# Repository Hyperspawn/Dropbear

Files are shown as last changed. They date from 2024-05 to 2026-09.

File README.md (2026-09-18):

<p align="center">
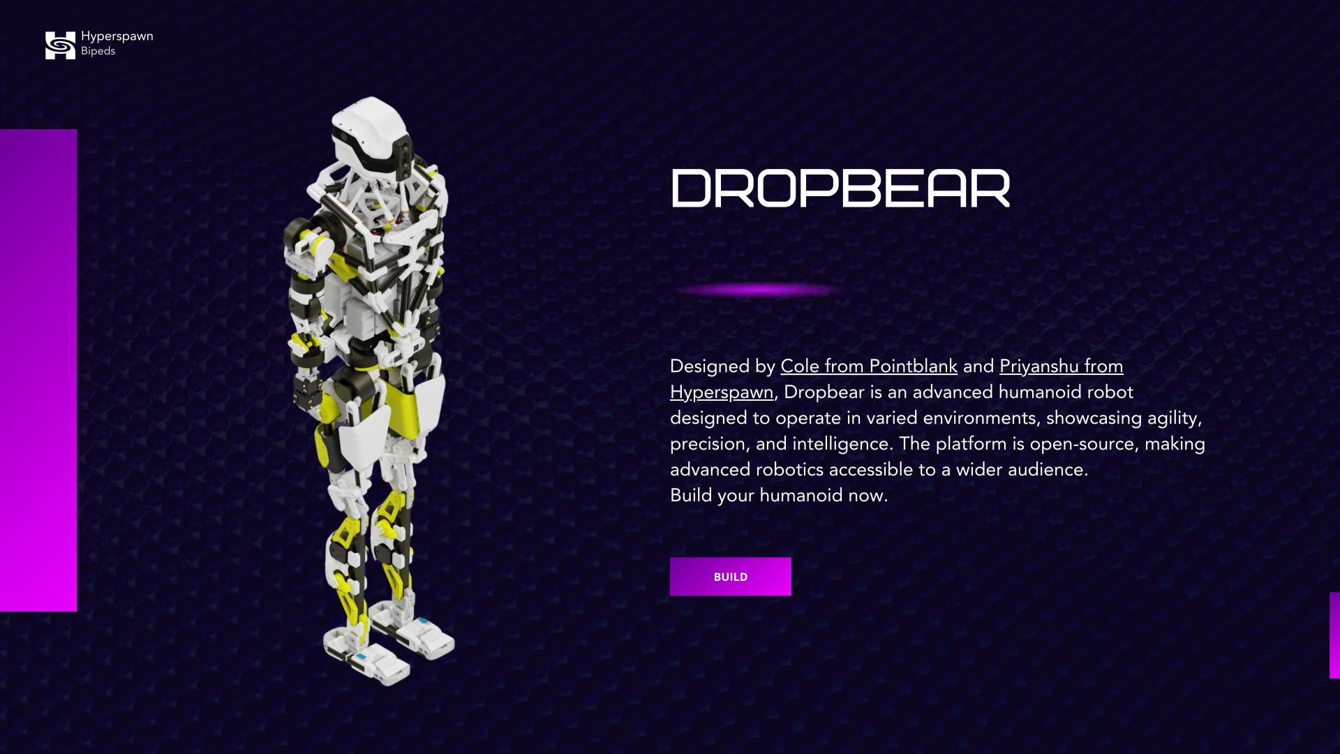
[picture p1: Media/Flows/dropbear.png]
Dropbear humanoid robot
  
</p>

# Dropbear

### A humanoid you can build, understand, and make your own.

Dropbear is a full-size humanoid robotics project by [Hyperspawn](https://hyperspawn.org) and [Pointblank](https://www.pointblankllc.com/). Mechanical designs, printable parts, robot models, and control research give you places to start across the whole robot—from a single assembly on your workbench to locomotion experiments in simulation.

The aim is to make building and using a humanoid feel approachable: find the parts, see how they fit, try a movement, understand what happened, and keep improving it. The [platform](https://hyperspawn.org/platform) brings the build and robot tools into one place.

**[Open the platform →](https://hyperspawn.org/platform)** · [Try the simulator](https://hyperspawn.org/sim) · [Explore the hardware](https://github.com/Hyperspawn/dropbear_hardware) · [Join the community](https://hyperspawn.org/community)

## Start with something you can do today

| I want to… | Start here | First step |
|---|---|---|
| Explore Dropbear | [Browser simulator](https://hyperspawn.org/sim) | Open the scene and explore the robot before setting up a development environment. |
| Build my own | [Build platform](https://hyperspawn.org/platform) | Open the Workshop, choose an assembly, and review its parts and prints. |
| Print a part or assemble a limb | [Printable parts](https://github.com/Hyperspawn/dropbear_printables) | Choose a subassembly and open its prepared `.3mf` plates or individual STL files. |
| Work on walking | [Locomotion](https://github.com/Hyperspawn/dropbear-locomotion) | Follow the setup guide, load a published checkpoint, and use the interactive viewer. |
| Observe connected controllers | [dropbear_control](https://github.com/robit-man/dropbear_control) | Run the local dashboard, open `/?live=1`, and use the Devices view for receive-only leg state and firmware diagnostics. |
| Change the mechanical design | [Hardware](https://github.com/Hyperspawn/dropbear_hardware) | Open the full assembly or a component in CAD. |

You can begin with a head, an arm, or a simulated robot. Each is a useful project in its own right.

## Connected robot control and firmware

Use [`robit-man/dropbear_control`](https://github.com/robit-man/dropbear_control) for the browser digital twin, live USB leg observation, raw serial diagnostics, controller health, and guarded firmware compilation/upload. Its physical command channel remains locked behind staged acknowledgements; live observation starts as receive-only.

```bash
git clone https://github.com/robit-man/dropbear_control.git
cd dropbear_control
python3 web/serve.py 8000
```

Open <http://localhost:8000/?live=1&renderer=swiftshader>. Select **Connected ESP32 devices** to inspect both leg streams, compile a trusted firmware source, or review an upload before its physical safety interlock is released.

The controller sources live in [`Control System/Low Level Control`](https://github.com/Hyperspawn/Dropbear/tree/main/Control%20System/Low%20Level%20Control):

| Firmware | Use |
|---|---|
| [`firmware_full_libs_neck.ino`](https://github.com/Hyperspawn/Dropbear/blob/main/Control%20System/Low%20Level%20Control/firmware_full_libs_neck.ino) | Recommended universal Behemoth image. One build supports left leg, right leg, center IMU, or head/neck roles, exposes the role-named captive portal, boots leg output stopped, and guards web motion with an expiring three-stage interlock. |
| [`esp32_devkitc_v4_hybrid.ino`](https://github.com/Hyperspawn/Dropbear/blob/main/Control%20System/Low%20Level%20Control/esp32_devkitc_v4_hybrid.ino) | Hybrid leg controller retained for existing PWM/CAN deployments. |
| [`esp32_devkit_v1_observation_safe.ino`](https://github.com/Hyperspawn/Dropbear/blob/main/Control%20System/Low%20Level%20Control/esp32_devkit_v1_observation_safe.ino) | Observation-only migration image. Motion commands stay disabled while five AS5600 and six motor-native CAN angles are reported. |
| [`esp32_devkit_v1.ino`](https://github.com/Hyperspawn/Dropbear/blob/main/Control%20System/Low%20Level%20Control/esp32_devkit_v1.ino) | Legacy/development leg controller. Keep it for compatibility and comparison; use Behemoth for new universal deployments. |

Read the [low-level firmware guide](https://github.com/Hyperspawn/Dropbear/blob/main/Control%20System/Low%20Level%20Control/README.md) and [Behemoth role/commissioning guide](https://github.com/Hyperspawn/Dropbear/blob/main/Control%20System/Low%20Level%20Control/BEHEMOTH.md) before selecting an image. The tracked [`partitions.csv`](https://github.com/Hyperspawn/Dropbear/blob/main/Control%20System/Low%20Level%20Control/partitions.csv) gives the application 2.5 MiB while retaining the Arduino default SPIFFS settings region at `0x290000`. The `dropbear_control` uploader reads the connected ESP32 partition table first and refuses a mismatched layout.

## From files to a robot on your workbench

The design is split into subassemblies so you can inspect, print, assemble, and revise one part at a time. The hardware repository includes full-robot STEP and Fusion archives, alongside separate arms, legs, head, pelvis, and torso designs. The print repository organizes parts and plates by assembly.

<p align="center">
  <a href="https://github.com/Hyperspawn/dropbear_hardware">
    CAD render of the Dropbear right arm assembly
    CAD render of the Dropbear right leg assembly
  </a>
</p>

*Right arm and right leg CAD renders from the hardware repository.*

1. **Choose your assembly.** Use the [Workshop](https://hyperspawn.org/platform/build) and [CAD files](https://github.com/Hyperspawn/dropbear_hardware) to understand the parts and how they connect.
2. **Plan the parts and prints.** Review the [bill of materials](https://github.com/Hyperspawn/dropbear_bom/blob/main/bom.md), then select the matching [print files and settings](https://github.com/Hyperspawn/dropbear_printables). You can print them yourself or use a print service.
3. **Assemble and document.** Follow the relevant [assembly documentation](https://github.com/Hyperspawn/dropbear_docs/tree/main/docs/03-assembly). Keep track of the design revision, substitutions, and anything the next builder should know.
4. **Bring up one subsystem at a time.** Review the [current low-level control source](https://github.com/Hyperspawn/Dropbear/tree/main/Control%20System/Low%20Level%20Control) and use [dropbear_control](https://github.com/robit-man/dropbear_control) for versioned observation, health, compile, and guarded upload. Establish wiring, joint directions, limits, and calibration before attempting coordinated motion.

Build files, documentation, and control software are evolving at different speeds. Match revisions across them before ordering parts or powering an assembly. Use the BOM to develop a budget for your chosen configuration and local suppliers.

## Walking you can inspect and reproduce

The [Dropbear locomotion project](https://github.com/Hyperspawn/dropbear-locomotion) publishes an Isaac Lab training environment, robot USD, policy checkpoints, evaluation reports, and an interactive viewer. You can load a policy, steer a simulated Dropbear, inspect its motion, and continue training.

Dropbear locomotion training shown in the interactive viewer (https://github.com/Hyperspawn/dropbear-locomotion)

*Isaac Lab simulation, with a training environment mirrored into the live viewer.*

The published **v0.1.0 flat-ground policy completed 128 simulation trials with zero falls**: 32 each for forward, backward, left, and right commands. Each trial ran for 20 seconds on a plane, with pushes disabled and a commanded speed of 0.20 m/s. Backward and lateral speed tracking remain areas for improvement. [Read the evaluation results](https://github.com/Hyperspawn/dropbear-locomotion/blob/main/evaluation/cardinal_0.20_strict_128.json).

The **v0.2.0 terrain checkpoint is experimental**, adding terrain observations and low-obstacle training. These are simulation releases; physical walking and robustness require separate validation.

**[Run the locomotion quick start →](https://github.com/Hyperspawn/dropbear-locomotion#quick-start)**

## Find the part of the project you need

This repository is the project’s front door and contains the original hardware, software, and media. More focused work lives in the repositories below.

| Area | Repository | What you will find |
|---|---|---|
| Mechanical design | [dropbear_hardware](https://github.com/Hyperspawn/dropbear_hardware) | Full assembly CAD and mechanical subassemblies. |
| 3D printing | [dropbear_printables](https://github.com/Hyperspawn/dropbear_printables) | Prepared print plates, individual parts, and print guidance. |
| Parts and sourcing | [dropbear_bom](https://github.com/Hyperspawn/dropbear_bom) | Purchased components and assembly-level cost estimates. |
| Build documentation | [dropbear_docs](https://github.com/Hyperspawn/dropbear_docs) | Assembly guides and sections for electronics, calibration, testing, and operation. |
| Robot descriptions | [dropbear_urdf](https://github.com/Hyperspawn/dropbear_urdf) · [dropbear_mjcf](https://github.com/Hyperspawn/dropbear_mjcf) | Robot models and meshes for visualization and simulation. |
| Simulation workspace | [dropbear_sim](https://github.com/Hyperspawn/dropbear_sim) | Links and submodules for the simulation projects. |
| Locomotion research | [dropbear-locomotion](https://github.com/Hyperspawn/dropbear-locomotion) | Training, published policies, live viewing, and evaluations. |
| Embedded control | [Current low-level control](https://github.com/Hyperspawn/Dropbear/tree/main/Control%20System/Low%20Level%20Control) · [dropbear_control](https://github.com/robit-man/dropbear_control) | Versioned ESP32/CAN firmware plus the connected-robot dashboard, diagnostics, compile, and guarded upload workflow. |
| Motor tools | [myactuator-can](https://github.com/Hyperspawn/myactuator-can) | MyActuator driver and diagnostics work. |

[Browse all Hyperspawn repositories →](https://github.com/orgs/Hyperspawn/repositories)

## What we are working toward

We want a humanoid that people can understand well enough to repair, adapt, teach, and put to use. That means connecting the practical details—parts, wiring, calibration, and control—with simulation, teleoperation, and learned behavior.

The next steps include more complete build guidance, better locomotion across terrain, and bringing control and learning workflows onto physical hardware. Teleoperation and language-driven behavior are development directions; their integration into a dependable whole-robot system is ongoing.

The useful unit of progress is something another person can try: a better joint, a clearer assembly step, a reproducible policy, or a physical test with enough detail to repeat it.

## Build with us

Share a build photo, improve a part, reproduce an experiment, or fix the instruction that slowed you down. Small improvements travel a long way when the next person builds from the same files.

- **Building hardware?** Include the assembly revision, material, print settings, and photos of the fit or failure.
- **Working on software or policies?** Include the environment, configuration, and results; say whether the test ran in simulation or on hardware.
- **Improving documentation?** Show the missing step, the corrected part, or the explanation you wish you had.

Open an issue or pull request in the relevant repository. For general project questions, use [Dropbear issues](https://github.com/Hyperspawn/Dropbear/issues) or the [community](https://hyperspawn.org/community). The documentation project also has [contribution guidelines](https://github.com/Hyperspawn/dropbear_docs/blob/main/CONTRIBUTING.md).

## Credits and licensing

Dropbear is developed by **Hyperspawn and Pointblank**, with contributions from builders and researchers across the project. Locomotion training lineage and contributor credits are documented in the [locomotion repository](https://github.com/Hyperspawn/dropbear-locomotion#training-lineage-and-credits).

This repository uses the [Hyperspawn License](https://github.com/Hyperspawn/Dropbear/blob/main/LICENSE), which restricts use to non-commercial purposes and requires a separate license for commercial use. Related repositories and assets carry their own terms; check the license supplied with the files you use.

---

[Start a build](https://hyperspawn.org/platform) · [Try the simulator](https://hyperspawn.org/sim) · [Meet the community](https://hyperspawn.org/community)

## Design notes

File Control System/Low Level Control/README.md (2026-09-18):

# Dropbear ESP32 Low-Level Control

Dropbear control hardware

Low-level ESP32 firmware for the Dropbear bipedal robot.

For connected-robot visualization, receive-only USB telemetry, raw controller
serial, and guarded compile/upload, use the
[`dropbear_control` dashboard](https://github.com/robit-man/dropbear_control).
The firmware choices in this directory are:

| Source | Intended use |
|---|---|
| `firmware_full_libs_neck.ino` | Recommended universal Behemoth build for left leg, right leg, center, and head/neck roles. Its role-named captive portal exposes live CAN/AS5600 state and guarded control; leg output boots stopped and web motion requires the timed three-stage interlock. |
| `esp32_devkitc_v4_hybrid.ino` | Existing hybrid leg PWM/CAN deployments. |
| `esp32_devkit_v1_observation_safe.ino` | Fail-closed observation migration with no motion command path. |
| `esp32_devkit_v1.ino` | Legacy/development leg implementation retained for compatibility. |

## Dashboard observation protocol

All four images answer `version`, `/version`, `capabilities`, and `health` on
USB Serial. They also accept `observe on` and `observe off`; these commands
only select telemetry and never change `playMode` or motor output.

Behemoth requires every command to carry its saved role, for example:

```text
<DB1:LEFTLEG> version
<DB1:RIGHTLEG> health
<DB1:RIGHTLEG> observe on
```

Hybrid, V1, and Observation Safe retain bare legacy command framing. The
firmware reports the exact choice instead of making the host guess:

```text
DBV1,<role>,<firmware>,<command_protocol>,<telemetry_protocol>,<capability;list>
DBH1,<role>,<ms>,<overall>,<runtime>,<can>,<sensor_mask>,<motor_fresh_mask>,<motor_control_mask>,<alignment_fault_mask>,<queries>,<responses>,<query_failures>,<malformed>,<can_failures>
```

Behemoth, Hybrid, and V1 emit `DB3`: five external sensor degrees, six raw
RMD `0x92` multi-turn degrees, six CAN angles aligned at restart to the
external sensor coordinates, then three six-bit freshness/control/fault masks.
Observation Safe emits `DB2` with the five external and six raw CAN fields.
The captive portals expose the same identity at `GET /api/version`.

All dashboard builds copy this directory's `partitions.csv`. It provides a
2.5 MiB application region while preserving the standard deployed SPIFFS
settings region at `0x290000` with size `0x160000`. The dashboard uses
`EraseFlash=none`, reads the target partition table before upload, and holds
the upload if the installed SPIFFS offset or size differs.

This controller is designed around **one ESP32 per leg**, an **MCP2515 CAN controller**, MyActuator/RMD-class CAN actuators, and five external analog joint-angle sensors per leg. The firmware performs high-rate joint sensing, optional joint-space impedance control, deterministic CAN torque output, persistent calibration/configuration, and serial command handling.

The current firmware is intentionally a **torque-control architecture**, not an actuator-internal absolute-position architecture. It sends MyActuator `0xA1` torque/current commands during normal operation and `0x81` stop commands when stopping a leg.

The firmware file documented here is:

```text
Control System/
└── Low Level Control/
    └── esp32_devkit_v1.ino
```

---

## Contents

- [System architecture](#system-architecture)
- [Controller roles](#controller-roles)
- [Hardware](#hardware)
- [Pinout](#pinout)
- [CAN configuration](#can-configuration)
- [Actuator IDs](#actuator-ids)
- [External joint sensors](#external-joint-sensors)
- [Boot sequence](#boot-sequence)
- [FreeRTOS runtime architecture](#freertos-runtime-architecture)
- [CAN command arbitration](#can-command-arbitration)
- [Direct torque control](#direct-torque-control)
- [Impedance control](#impedance-control)
- [Joint constraints](#joint-constraints)
- [Sensor calibration](#sensor-calibration)
- [Torque-direction calibration](#torque-direction-calibration)
- [Stop behavior](#stop-behavior)
- [Center / IMU mode](#center--imu-mode)
- [Persistent configuration](#persistent-configuration)
- [Serial interface](#serial-interface)
- [Command reference](#command-reference)
- [Recommended commissioning procedure](#recommended-commissioning-procedure)
- [Safety and current limitations](#safety-and-current-limitations)
- [Dependencies](#dependencies)
- [Relationship to `myactuator-can`](#relationship-to-myactuator-can)
- [Legacy behavior removed or changed](#legacy-behavior-removed-or-changed)

---

# System architecture

The controller is split into three primary real-time paths:

```text
                         HIGH-LEVEL / SERIAL COMMAND
                                   │
                  ┌────────────────┴────────────────┐
                  │                                 │
          direct torque setpoint            impedance target
                  │                                 │
                  │                          q*, dq*
                  │                                 │
                  │                    external joint sensor
                  │                                 │
                  │                          state estimate
                  │                                 │
                  │                     impedance controller
                  │                                 │
                  └──────────────┬──────────────────┘
                                 │
                          command selection
                                 │
                         torque saturation
                                 │
                         single CAN writer
                                 │
                    MyActuator 0xA1 command
                                 │
                              actuator
```

The key architectural rule is:

> **Only the CAN output task performs normal actuator transmission.**

The impedance task computes desired torque but does not transmit CAN frames. Direct torque commands also only update setpoints. The CAN output task is the single periodic owner of normal motor output.

This prevents the previous architecture from having multiple FreeRTOS tasks independently transmit competing torque values to the same actuator.

---

# Controller roles

Each ESP32 stores one of three roles in SPIFFS:

```text
left
right
center
```

## `left`

The controller:

- initializes MCP2515 CAN,
- reads the five local analog joint sensors,
- runs left-leg impedance controllers,
- sends commands only to the six left-leg actuator CAN IDs,
- accepts left-leg torque and impedance commands.

## `right`

The controller:

- initializes MCP2515 CAN,
- reads the five local analog joint sensors,
- runs right-leg impedance controllers,
- sends commands only to the six right-leg actuator CAN IDs,
- accepts right-leg torque and impedance commands.

## `center`

The controller:

- does not initialize the MCP2515 CAN control path,
- does not start leg sensor/control/CAN-output tasks,
- starts the IMU polling task,
- polls I²C addresses `0x68` through `0x6C`,
- prints raw accelerometer and gyroscope data over Serial.

Changing between a leg role and `center` is persisted immediately, but **a reboot is required for the correct task/hardware set to be created**.

Changing directly between `left` and `right` uses the same leg task set and can take effect without changing the physical task topology, although the robot should still be stopped before changing roles.

---

# Hardware

The current low-level leg controller expects:

- ESP32 DevKit V1 / classic ESP32
- MCP2515 CAN controller
- MCP2515 module fitted with an **8 MHz oscillator**
- CAN transceiver associated with the MCP2515 module
- MyActuator/RMD-compatible CAN actuators
- five analog joint-angle signals per leg
- optional I²C IMUs for center mode
- USB serial connection for configuration/debugging

The code uses a 12-bit ADC configuration:

```cpp
analogReadResolution(12);
```

which produces nominal readings from `0` through `4095`.

---

# Pinout

## MCP2515 / SPI

| Function | ESP32 GPIO | Notes |
| --- | ---: | --- |
| MCP2515 CS  | **5** | Active chip-select used by `MCP_CAN` |
| SPI SCK | **18** | Explicitly initialized |
| SPI MISO | **19** | Explicitly initialized |
| SPI MOSI | **23** | Explicitly initialized |
| MCP2515 INT | **17** | Configured as `INPUT_PULLUP`; current firmware does not use interrupt-driven CAN RX |

SPI initialization:

```cpp
SPI.begin(18, 19, 23, 5);
```

The current controller is transmit-oriented. The MCP2515 interrupt pin is retained in the hardware definition for future receive/interrupt handling, but no ISR is currently attached.

## I²C

| Function | ESP32 GPIO |
| --- | ---: |
| SDA | **21** |
| SCL | **22** |

Initialization:

```cpp
Wire.begin(21, 22);
```

## Analog joint sensors

| Joint measurement | ESP32 GPIO |
| --- | ---: |
| Outer calf | **14** |
| Inner calf | **27** |
| Hip pitch | **26** |
| Knee | **25** |
| Hip roll / butt | **33** |

There is currently **no dedicated external analog hip-yaw input**.

---

# CAN configuration

The MCP2515 is configured as:

```text
Bit rate:       1,000,000 bit/s
MCP2515 clock:  8 MHz
Mode:           normal
CAN frame type: standard 11-bit identifier
```

Initialization is equivalent to:

```cpp
CAN.begin(MCP_ANY, CAN_1000KBPS, MCP_8MHZ);
CAN.setMode(MCP_NORMAL);
```

If MCP2515 initialization fails, firmware prints an error and intentionally stops in an infinite delay loop rather than entering operation without CAN.

---

# Actuator IDs

The twelve robot actuator IDs are preserved.

| Internal index | Side  | Joint |  CAN ID |
| ---: | ----- | --- | ---: |
| 0 | Right | Outer calf | `0x144` |
| 1 | Left  | Outer calf | `0x141` |
| 2 | Right | Inner calf | `0x143` |
| 3 | Left  | Inner calf | `0x142` |
| 4 | Right | Knee | `0x148` |
| 5 | Left  | Knee | `0x145` |
| 6 | Right | Hip pitch  | `0x147` |
| 7 | Left  | Hip pitch  | `0x146` |
| 8 | Right | Hip yaw | `0x14C` |
| 9 | Left  | Hip yaw | `0x149` |
| 10 | Right | Hip roll | `0x14B` |
| 11 | Left  | Hip roll | `0x14A` |

The array is deliberately interleaved:

```text
even index -> right leg
odd index  -> left leg
```

This allows the CAN output task to select a leg with a stride of two.

### Left controller transmits only

```text
0x141
0x142
0x145
0x146
0x149
0x14A
```

### Right controller transmits only

```text
0x144
0x143
0x148
0x147
0x14C
0x14B
```

A left ESP therefore no longer sends zero or control traffic to right-leg motors, and a right ESP no longer sends traffic to left-leg motors.

---

# External joint sensors

Five local joint signals are sampled by each leg controller.

The processing chain is:

```text
ADC
 │
 ├─ 12-bit analogRead()
 │
 ├─ 10-sample moving average
 │
 ├─ convert ADC count to 0..360 degrees
 │
 ├─ apply selected-leg offset unless raw mode is enabled
 │
 └─ wrap result into [0, 360)
```

ADC-to-angle conversion is:

```text
angle = ADC × 360 / 4096
```

## Sensor acquisition rate

The sensor task runs every:

```text
1 ms
```

or approximately:

```text
1000 Hz
```

The moving-average window is ten samples, so the filter spans approximately 10 ms at the nominal task rate.

## Serial telemetry rate

When `playMode` is active in leg mode, normalized angles are printed approximately every:

```text
20 ms
```

or:

```text
50 Hz
```

The telemetry format is CSV:

```text
outer,inner,hipPitch,knee,hipRoll
```

Example:

```text
181.2,179.7,176.4,183.1,180.0
```

Command/status text shares the same Serial connection, so consumers of the stream must be able to distinguish CSV telemetry lines from human-readable command responses.

---

# Boot sequence

On reset, the firmware performs the following sequence.

## 1. Serial

Starts:

```text
115200 baud
```

## 2. Synchronization primitives

Creates:

- serial mutex,
- CAN mutex,
- state mutex.

## 3. ADC and I²C

Configures 12-bit ADC resolution and starts I²C on GPIO 21/22.

## 4. SPIFFS

Mounts SPIFFS using:

```cpp
SPIFFS.begin(true)
```

The `true` argument allows formatting if mounting fails.

If SPIFFS still cannot be mounted, the controller halts.

## 5. Configuration

The firmware attempts to load:

```text
/config.txt
```

If no configuration file exists, the controller prompts:

```text
Enter 'left' for left leg, 'right' for right leg, or 'center' for IMU center.
```

The selected role is then saved.

## 6. Role-specific initialization

### Leg role

The controller:

1. configures MCP2515 INT GPIO 17 as input pull-up,
2. initializes SPI,
3. starts MCP2515 at 1 Mbit/s / 8 MHz,
4. switches MCP2515 to normal mode,
5. primes the ten-sample joint sensor filters,
6. starts sensor, impedance, CAN-output, and serial tasks.

### Center role

The controller starts:

- IMU task,
- serial-command task.

CAN is not initialized in center mode.

## 7. Play state

At the end of setup:

```cpp
playMode = true;
```

Therefore:

- a leg controller begins its normal 100 Hz CAN output loop immediately,
- all initial torque setpoints are zero, so initial normal output is zero `0xA1` torque,
- a center controller begins IMU polling immediately.

This startup behavior is intentional and preserves the previous controller's automatic active state while ensuring the initial commanded torque values are zero.

---

# FreeRTOS runtime architecture

## Leg controller tasks

| Task | Core | Priority | Period | Responsibility |
| --- | ---: | ---: | ---: | --- |
| `readAndComputeTask` | 0 | 2 | 1 ms | ADC acquisition, filtering, normalization, 50 Hz telemetry |
| `impedanceControlTask` | 1 | 2 | 10 ms | Compute impedance torque setpoints |
| `canOutputTask` | 1 | 3 | 10 ms | Sole periodic actuator CAN transmitter |
| `checkChiralityTask` | 1 | 1 | ~10 ms poll | Serial command parser |

## Center controller tasks

| Task | Core | Priority | Period | Responsibility |
| --- | ---: | ---: | ---: | --- |
| `imuReadTask` | 0 | 1 | 10 ms | Poll raw IMU data |
| `checkChiralityTask` | 1 | 1 | ~10 ms poll | Serial command parser |

The Arduino `loop()` does not implement control logic. It simply sleeps while FreeRTOS tasks own the runtime.

---

# CAN command arbitration

The CAN output task has an explicit command priority.

```text
1. calibration override
        ↓
2. play-mode command output
        ↓
3. queued stop burst
        ↓
4. no transmission
```

## 1. Calibration override

When torque-direction calibration is active:

- only the selected test joint receives the requested test torque,
- every other motor on the selected leg receives zero torque,
- normal direct/impedance setpoints are ignored until calibration ends.

## 2. Normal play output

For each of the six actuators belonging to this controller:

```text
if impedance is enabled for that joint:
    transmit impedanceTorqueValues[joint]
else:
    transmit torqueValues[joint]
```

The selected torque is clamped before transmission.

## 3. Stop burst

When stopped, three `0x81` stop frames are sent to every motor on the selected leg, one burst per CAN task period.

At a 10 ms CAN task rate, this normally means:

```text
t = 0 ms   stop each of six motors
t = 10 ms  stop each of six motors
t = 20 ms  stop each of six motors
```

After the third burst, the controller remains silent until `play` is enabled again.

---

# Direct torque control

Normal direct motor commands use MyActuator command byte:

```text
0xA1
```

The frame generated by the firmware is:

```text
Byte 0: 0xA1
Byte 1: 0x00
Byte 2: 0x00
Byte 3: 0x00
Byte 4: torque low byte
Byte 5: torque high byte
Byte 6: 0x00
Byte 7: 0x00
```

The torque value is transmitted as a signed 16-bit value.

## Torque limit

The firmware currently defines:

```cpp
float maxTorqueLimit = 3.0f;
```

and converts this to a command clamp of:

```text
±300 firmware torque units
```

because the internal clamp is:

```text
maxTorqueLimit × 100
```

This preserves the scaling behavior of the existing A1 implementation. Actual motor current/torque interpretation depends on the actuator's MyActuator/RMD protocol and motor configuration.

## Manual command example

```text
torque left knee 100
```

sets the left-knee direct torque setpoint to `100`.

The value is not transmitted directly by the command parser. It is stored, and the CAN output task transmits the active setpoint at 100 Hz while `playMode` is enabled.

## Chirality enforcement

If a command addresses the opposite leg, it is rejected.

Example on a controller configured as `left`:

```text
torque right knee 100
```

returns a rejection rather than transmitting to the right knee.

---

# Impedance control

Impedance control is available for joints with external analog joint sensing:

```text
outer_calf
inner_calf
knee
hip_pitch
hip_roll
```

Hip yaw is **direct-torque only** in the current firmware because no external hip-yaw analog sensor is mapped.

## Control law

The implemented controller is:

```text
τ = K(q* - q) + D(dq* - dq) + M(ddq)
```

where:

- `q*` = desired position,
- `q` = measured joint position,
- `dq*` = desired velocity,
- `dq` = estimated velocity,
- `ddq` = estimated acceleration,
- `K` = stiffness,
- `D` = damping,
- `M` = acceleration/feed-forward coefficient used by the existing controller.

The computed result is clamped to the same global torque limit used for manual torque commands.

## Default controller constants

| Joint | Damping `D` | Stiffness `K` | Mass/accel coefficient `M` |
| --- | ---: | ---: | ---: |
| Outer calf | 2.5 | 50.0 | 0.8 |
| Inner calf | 2.5 | 50.0 | 0.8 |
| Knee | 3.0 | 60.0 | 3.55 |
| Hip pitch  | 3.5 | 80.0 | 9.05 |
| Hip roll | 3.5 | 80.0 | 9.05 |

Separate controller instances exist for left and right joints.

## Impedance update rate

The impedance task runs every:

```text
10 ms
```

or approximately:

```text
100 Hz
```

## Derivative initialization

When an impedance controller is first enabled or reset, its previous position and time are initialized before derivative terms are used. This avoids the large first-cycle velocity/acceleration spike produced by treating an uninitialized previous state as valid history.

## Direction multipliers

The calculated impedance torque is multiplied by the saved direction multiplier for the corresponding joint before transmission.

Direction multipliers are currently implemented for:

- outer calf,
- inner calf,
- knee,
- hip pitch,
- hip roll,

on both legs.

Hip yaw has no impedance controller or direction multiplier in the current firmware.

## Impedance command example

```text
impedance left knee 1 180 0
```

means:

```text
leg:              left
joint:            knee
enabled:          yes
desired position: 180 degrees
desired velocity: 0 degrees/s
```

Disable it with:

```text
impedance left knee 0 180 0
```

When impedance is enabled for a joint, its impedance output has precedence over that joint's stored direct torque value.

Disabling impedance causes the CAN output path to fall back to the stored direct torque setpoint for that joint.

---

# Joint constraints

Each joint has:

```text
minimum angle
maximum angle
```

Default constraints are:

```text
0 .. 360 degrees
```

The constraints are persistent.

## Constraint behavior

Constraints currently protect the **impedance controller**.

Before calculating impedance torque:

```text
if actualPosition < minAngle
or actualPosition > maxAngle:
    impedance torque = 0
    controller derivative state is reset
```

Important:

> **Direct `torque` commands do not currently enforce angle constraints.**

Joint constraints therefore must not be treated as a universal hard-stop mechanism.

## Direct constraint command

Example:

```text
constrain knee_left 20 165
```

Supported constraint names:

```text
outer_calf_left
outer_calf_right
inner_calf_left
inner_calf_right
knee_left
knee_right
hip_pitch_left
hip_pitch_right
hip_yaw_left
hip_yaw_right
hip_roll_left
hip_roll_right
```

Hip-yaw constraints are stored but are not currently consumed by an impedance controller because hip yaw has no mapped external sensor.

There is also an interactive:

```text
setJointConstraints
```

command.

---

# Sensor calibration

The `calibrate` command calibrates the five analog joint inputs for the currently selected leg.

The calibration procedure:

1. takes a fresh ten-sample sensor average,
2. converts each sensor to degrees,
3. calculates an offset that makes the current physical pose equal to `180°`,
4. updates the selected leg's offsets in RAM,
5. asks whether those offsets should be written to SPIFFS.

For every sensor:

```text
offset = 180 - rawAngle
```

The five resulting offsets correspond to:

```text
outer calf
inner calf
hip pitch
knee
hip roll
```

The prompt is:

```text
Type 'yes' to save these offsets, anything else to leave them only in RAM.
```

Calibration is unavailable in `center` mode.

## Default hardcoded offsets

If no persisted configuration overrides them, the source contains:

### Left

```text
outer calf:  +32
inner calf:  -26
hip pitch:    -4
knee:        -17
hip roll:     +2
```

### Right

```text
outer calf:  -28
inner calf:  +39
hip pitch:    -2
knee:        +18
hip roll:     -2
```

`resetOffsets` sets **both** left and right stored offset arrays to zero and immediately saves the configuration.

---

# Torque-direction calibration

The firmware can determine the sign multiplier for a sensor-backed joint.

Example:

```text
calibrateDirection left_knee
```

Supported joint names:

```text
left_outer_calf
left_inner_calf
left_knee
left_hip_pitch
left_hip_roll

right_outer_calf
right_inner_calf
right_knee
right_hip_pitch
right_hip_roll
```

The requested joint must belong to the controller's current chirality.

## Calibration algorithm

The firmware:

1. reads the joint's external analog encoder,
2. enables calibration override,
3. tests positive torque commands from `10` through `150` in increments of `10`,
4. holds each test value for approximately `500 ms`,
5. checks whether the encoder moved by more than 10 raw converted degrees/count-equivalent output units,
6. if movement is detected, determines the multiplier from movement direction,
7. otherwise repeats the procedure from `-10` through `-150`,
8. zeros the test motor,
9. leaves calibration override,
10. saves the detected multiplier.

During calibration:

- the test actuator receives the calibration command,
- all other actuators on that leg are actively commanded to zero,
- the normal play/impedance output path does not compete for CAN ownership.

This procedure can physically move a joint for several seconds and must only be performed with the robot mechanically supported and with a physical emergency-stop strategy available.

---

# Stop behavior

The normal stop command is:

```text
stop
```

It performs:

```text
playMode = false
stopBurstRemaining = 3
```

The CAN output task then sends the MyActuator stop command:

```text
0x81
```

to the **actual six actuator CAN IDs for the selected leg**.

This corrects the previous firmware behavior that could iterate numeric values `0..11` rather than the real actuator IDs.

The `0x81` frame is:

```text
81 00 00 00 00 00 00 00
```

After three complete stop bursts, normal CAN transmission stops.

## Resume

Use:

```text
play
```

to resume periodic output.

In leg mode, `play` also clears any pending stop-burst count.

## `zero` is not the same as `stop`

`zero` clears:

- direct torque setpoints,
- current stored impedance torque outputs.

It does **not** disable impedance controllers.

Therefore an enabled impedance controller can calculate a new nonzero torque again on its next 100 Hz update.

For an actual stop condition use:

```text
stop
```

not only:

```text
zero
```

---

# Center / IMU mode

A controller configured as:

```text
center
```

does not start the leg CAN-control path.

The IMU task runs at approximately:

```text
100 Hz
```

and attempts to poll five I²C addresses:

```text
0x68
0x69
0x6A
0x6B
0x6C
```

For each responding address it:

1. writes register address `0x3B`,
2. requests 14 bytes,
3. reads:
   - accelerometer X,
   - accelerometer Y,
   - accelerometer Z,
   - skips temperature,
   - gyroscope X,
   - gyroscope Y,
   - gyroscope Z,
4. prints the raw values over Serial.

Output format:

```text
IMU <index> Acc:<ax>,<ay>,<az> Gyro:<gx>,<gy>,<gz>
```

The firmware does **not** currently:

- configure IMU operating registers,
- convert raw data to SI units,
- perform orientation fusion,
- select channels on an I²C multiplexer,
- process magnetometer data.

It assumes devices are already directly addressable and readable at the addresses above.

---

# Persistent configuration

Configuration is stored in:

```text
/config.txt
```

inside SPIFFS.

The saved data includes:

- controller role (`left`, `right`, or `center`),
- left offsets,
- right offsets,
- ten torque-direction multipliers,
- all left/right joint constraints.

The file is rewritten by `saveConfig()`.

A representative structure is:

```text
LegSide:left
LeftOffsets:32,-26,-4,-17,2
RightOffsets:-28,39,-2,18,-2
DirectionMultipliers:1.000000,1.000000,1.000000,1.000000,1.000000,1.000000,1.000000,1.000000,1.000000,1.000000
outer_calf_left_Constraints Constraints:0,360
outer_calf_right_Constraints Constraints:0,360
inner_calf_left_Constraints Constraints:0,360
inner_calf_right_Constraints Constraints:0,360
knee_left_Constraints Constraints:0,360
knee_right_Constraints Constraints:0,360
hip_pitch_left_Constraints Constraints:0,360
hip_pitch_right_Constraints Constraints:0,360
hip_yaw_left_Constraints Constraints:0,360
hip_yaw_right_Constraints Constraints:0,360
hip_roll_left_Constraints Constraints:0,360
hip_roll_right_Constraints Constraints:0,360
```

The loader now searches each constraint line for `Constraints:` rather than requiring the line itself to begin with that token. This makes the saved and loaded formats consistent.

## `resetSPIFFS`

Despite its legacy name, the current `resetSPIFFS` command is primarily an **integrity check**.

If `SPIFFS.totalBytes()` is nonzero it reports that SPIFFS is functioning.

If total size is zero, it prompts for confirmation before formatting.

It does **not** normally delete `/config.txt` or reset a healthy filesystem to defaults.

---

# Serial interface

Use:

```text
115200 baud
```

with newline-terminated commands.

The serial command task checks for input approximately every 10 ms.

Normal mode and configuration mode have different accepted command sets.

---

# Command reference

## `help`

Print the full firmware command list.

```text
help
```

---

## `status`

Print current operating state.

```text
status
```

Example fields:

```text
mode
chirality
play
raw
maxTorque
```

In leg mode it also prints the five normalized joint angles.

---

## `chirality`

Print the currently selected controller role.

```text
chirality
```

Possible responses:

```text
left
right
center
```

---

## `left`

Set controller role to left leg and persist it.

```text
left
```

If currently operating as a leg controller, a stop burst is issued first.

---

## `right`

Set controller role to right leg and persist it.

```text
right
```

If currently operating as a leg controller, a stop burst is issued first.

---

## `center`

Set controller role to center/IMU mode and persist it.

```text
center
```

A reboot is required to instantiate the center-mode task topology.

---

## `play`

Enable active output.

```text
play
```

### Leg mode

- cancels any pending stop burst,
- enables 100 Hz torque output.

### Center mode

- enables IMU streaming.

---

## `stop`

Disable play mode and queue three stop bursts.

```text
stop
```

In leg mode this sends `0x81` to all six selected-leg actuator IDs three times.

---

## `zero`

Clear all stored direct and impedance torque values.

```text
zero
```

This does not disable impedance controllers and is not a replacement for `stop`.

---

## `torque`

Set a direct torque command.

Syntax:

```text
torque <legSide> <appendage> <torqueValue>
```

Examples:

```text
torque left knee 100
torque left knee -100
torque right hip_yaw 40
```

Valid appendages:

```text
outer_calf
inner_calf
knee
hip_pitch
hip_yaw
hip_roll
```

The leg side must match the controller's selected chirality.

The command value is clamped to the firmware's current global limit.

---

## `impedance`

Enable/disable impedance control and assign desired state.

Syntax:

```text
impedance <legSide> <appendage> <0|1> <desiredPosition> <desiredVelocity>
```

Examples:

```text
impedance left knee 1 180 0
impedance left hip_pitch 1 170 0
impedance left knee 0 180 0
```

Supported appendages:

```text
outer_calf
inner_calf
knee
hip_pitch
hip_roll
```

Hip yaw is not supported in impedance mode.

The requested leg must match the controller's chirality.

---

## `direction`

Manually set the impedance torque direction multiplier.

Syntax:

```text
direction <joint> <+|->
```

Examples:

```text
direction left_knee +
direction right_outer_calf -
```

Supported joints:

```text
left_outer_calf
left_inner_calf
left_knee
left_hip_pitch
left_hip_roll
right_outer_calf
right_inner_calf
right_knee
right_hip_pitch
right_hip_roll
```

The multiplier is persisted immediately.

Direction multipliers are applied to the **impedance-control output**. Direct `torque` setpoints are sent with the sign supplied by the caller.

---

## `calibrateDirection`

Automatically determine direction multiplier from external joint motion.

Syntax:

```text
calibrateDirection <joint>
```

Example:

```text
calibrateDirection left_knee
```

Only sensor-backed joints are supported.

The joint must belong to the selected leg.

---

## `calibrate`

Calibrate all five analog sensors on the selected leg such that the current pose corresponds to 180°.

```text
calibrate
```

After calculating values, the controller prompts whether to persist them.

---

## `resetOffsets`

Set both left and right sensor offset arrays to zero and save.

```text
resetOffsets
```

---

## `raw on`

Disable offset application.

```text
raw on
```

The sensors remain filtered and converted to degrees, but saved offsets are bypassed.

---

## `raw off`

Re-enable offset application.

```text
raw off
```

---

## `saved`

Print the saved/current offsets for the selected leg.

```text
saved
```

---

## `save`

Rewrite the current configuration to SPIFFS.

```text
save
```

---

## `constrain`

Set and immediately persist one joint's impedance constraint.

Syntax:

```text
constrain <joint> <minAngle> <maxAngle>
```

Example:

```text
constrain knee_left 20 165
```

`minAngle` must be less than or equal to `maxAngle`.

---

## `setJointConstraints`

Interactive constraint setter.

```text
setJointConstraints
```

The controller prompts for:

1. joint name,
2. minimum angle,
3. maximum angle.

---

## `config`

Enter configuration mode.

```text
config
```

Entering configuration mode:

1. requests a three-burst actuator stop,
2. waits approximately 40 ms for the stop frames to be emitted,
3. enables `configMode`.

While in configuration mode, only the following commands are accepted:

```text
exit
left
right
center
calibrate
save
status
```

Other normal-mode commands are rejected as unknown configuration commands.

---

## `exit`

Only used while in configuration mode.

```text
exit
```

Exiting configuration mode does **not** automatically resume actuator output.

Use:

```text
play
```

explicitly when ready.

---

## `mac`

Print the ESP32 Wi-Fi MAC address.

```text
mac
```

Wi-Fi networking is not otherwise used by this firmware.

---

## `resetSPIFFS`

Check SPIFFS integrity and offer formatting only if the filesystem reports zero total bytes.

```text
resetSPIFFS
```

This is not a normal "erase all configuration" command.

---

# Recommended commissioning procedure

The following sequence is recommended whenever flashing a controller or changing actuator/sensor wiring.

## 1. Mechanically support the robot

Do not commission torque-controlled joints while the robot is free-standing.

Remove load where practical and keep a physical power-disconnect / E-stop available.

## 2. Flash the firmware

Upload `esp32_devkit_v1.ino`.

Open Serial Monitor at:

```text
115200
```

with newline line endings.

## 3. Select role on first boot

If `/config.txt` does not exist, enter:

```text
left
```

or:

```text
right
```

for a leg controller.

Use:

```text
center
```

only for the center/IMU controller.

## 4. Verify status

Run:

```text
status
chirality
```

Confirm that the leg matches the physical ESP32.

## 5. Stop before active tests

Run:

```text
stop
```

before calibration or intentional torque testing.

## 6. Verify sensor movement

Use:

```text
raw on
play
```

and observe the five-value CSV telemetry.

Move each mechanism manually and confirm that the expected sensor channel changes.

Then:

```text
stop
raw off
```

## 7. Calibrate offsets

Place the leg in the physical pose that should correspond to `180°` for each sensor and run:

```text
calibrate
```

Review the offsets and answer:

```text
yes
```

only if the pose and values are correct.

## 8. Set constraints

Example:

```text
constrain knee_left 20 165
```

Set realistic per-joint bounds before impedance testing.

Remember that these limits currently guard impedance output only.

## 9. Verify motor direction

With the mechanism unloaded/supported:

```text
calibrateDirection left_knee
```

Repeat for each externally sensed joint on the selected leg.

## 10. Test small direct torque

Example:

```text
torque left knee 10
play
```

Verify the expected direction.

Then:

```text
stop
zero
```

Increase test values gradually only after confirming behavior.

## 11. Test impedance conservatively

Begin near the measured current joint angle with zero desired velocity.

Example:

```text
impedance left knee 1 180 0
play
```

Keep a hardware stop available.

Use:

```text
stop
```

to stop output.

---

# Safety and current limitations

This is low-level robot actuator firmware. Several current properties are important.

## Partial CAN receive-state processing

All leg firmware variants continuously request and decode actuator position
with RMD V1.7/V4.2 command `0x92`. The five external sensors establish the absolute
joint reference after restart; fresh motor-native feedback then provides the
continuous position used by impedance control. Missing or stale CAN position
fails to zero torque instead of falling back to continuous external-sensor
control.

The firmware does not yet monitor, through CAN:

- actuator velocity,
- actuator current feedback,
- actuator temperature,
- motor fault flags,
- response families beyond position.

## No command watchdog

There is no high-level command heartbeat or timeout that automatically stops a leg when serial/high-level commands disappear.

Once `play` is enabled, the controller continues transmitting the latest selected setpoints until another command changes the state or `stop` is issued.

A production locomotion controller should add a supervisory watchdog.

## Legacy V1 startup enters play mode

The legacy `esp32_devkit_v1.ino` sets `playMode` true at the end of `setup()`.
The recommended Behemoth firmware boots with `playMode=false`; observation,
version, and health requests do not enable it.

Initial torque setpoints are zero, but the controller does begin active zero-torque A1 transmission automatically.

## Joint constraints do not protect direct torque mode

Constraints are checked by impedance controllers only.

A direct torque command can continue even when a joint is outside its configured impedance range.

## `zero` does not disable impedance

An enabled impedance controller can repopulate its torque output on the following control update.

Use `stop` for stopping the actuator command path.

## Angle wrap-around

Normalized analog joint angles are wrapped into:

```text
0 <= angle < 360
```

Velocity is currently estimated by direct subtraction of successive wrapped angles.

Crossing `359° -> 0°` or `0° -> 359°` can therefore appear as a large instantaneous position change.

Avoid placing operating trajectories across the wrap boundary until wrapped-angle derivative handling is added.

## Constraints do not currently support wrapped intervals

A simple numeric test is used:

```text
minAngle <= actualPosition <= maxAngle
```

A desired valid interval such as:

```text
330° through 30°
```

cannot currently be represented as a single wrapped constraint.

## Hip yaw has no external joint sensor path

Hip yaw can be directly torque-controlled but cannot currently use the external-sensor impedance loop.

## IMU polling is raw

Center mode does not initialize or fuse IMU devices. It only attempts raw register reads.

## MCP2515 interrupt is not consumed

GPIO17 is reserved/configured for MCP2515 INT, but the current firmware does not attach an interrupt handler or use CAN RX.

## Direction calibration causes intentional motion

`calibrateDirection` can test progressively larger positive and negative commands with roughly 500 ms dwell per step.

Do not run this routine on a loaded or unsupported leg.

---

# Dependencies

The sketch requires:

- Arduino Core for ESP32
- `mcp_can.h` / an MCP2515 CAN library exposing the `MCP_CAN` API
- SPI
- SPIFFS
- Wire / I²C
- WiFi library from the ESP32 Arduino core
- FreeRTOS support provided by the ESP32 Arduino core

The sketch includes:

```cpp
#include <Arduino.h>
#include <mcp_can.h>
#include <SPI.h>
#include <SPIFFS.h>
#include <Wire.h>
#include <WiFi.h>
#include <freertos/FreeRTOS.h>
#include <freertos/task.h>
#include <freertos/semphr.h>
#include <math.h>
```

Use an ESP32 partition configuration that provides SPIFFS storage.

---

# Relationship to `myactuator-can`

The low-level Dropbear controller and the `Hyperspawn/myactuator-can` repository use the same general ESP32 + MCP2515 + MyActuator ecosystem, but the control purposes are different.

`myactuator-can` is useful as a MyActuator CAN protocol/reference implementation.

The Dropbear leg controller intentionally retains a different locomotion architecture:

```text
Dropbear:
external joint sensor
    ↓
ESP32 control loop
    ↓
0xA1 torque command
    ↓
actuator
```

rather than the simpler actuator-internal absolute-position path:

```text
target angle
    ↓
ESP32
    ↓
0xA4 absolute-position command
    ↓
actuator internal position controller
```

For Dropbear's legs, the external joint sensors remain important as restart
absolute references and independent drift checks. Continuous position comes
from the motor-native CAN angle while torque-level output remains under the
ESP32 impedance controller.

The current Dropbear firmware therefore does **not** directly adopt the `myactuator-can` demo motor-ID layout or its `0xA4` position-control behavior.

---

# Legacy behavior removed or changed

This firmware revision changes several important behaviors from the previous low-level controller.

## Correct actuator stop IDs

Old behavior could call the stop function with numeric loop indexes.

Current behavior always sends `0x81` to the actual selected-leg actuator IDs.

## One CAN output authority

The old structure could allow a manual torque task and impedance task to independently send commands.

Current behavior uses one normal periodic CAN writer.

## Per-leg CAN isolation

A leg controller now sends only to its own six actuator IDs.

## Impedance parser fixed

Desired position and desired velocity are parsed as separate arguments.

## Persistent joint constraints fixed

The loader now correctly parses the format written by the saver.

## Center IMU task is actually started

A controller booted as `center` now creates the IMU polling task.

## Telemetry throttled

Sensor acquisition remains approximately 1 kHz, while serial angle telemetry is limited to approximately 50 Hz.

## Calibration output is arbitrated

Direction calibration now uses a dedicated output override rather than racing the normal CAN path.

## Removed legacy commands

The previous README referenced commands such as:

```text
stop_actuator
buzz_motor
```

These are **not commands in the current firmware** and should not be documented as supported.

---

# Development direction

Logical next low-level improvements include:

- command heartbeat/watchdog,
- physical E-stop input,
- bus-off/error recovery,
- actuator temperature/current/fault supervision,
- wrapped-angle-safe derivatives,
- universal hard joint limits applied to every control mode,
- hip-yaw external sensing,
- timestamped binary or structured telemetry,
- high-level command transport independent of debug Serial,
- explicit controller-state machine,
- IMU initialization and sensor fusion,
- deterministic configuration schema/versioning.

---

# License

This project is licensed under the repository's MIT License.

## Observation-only migration image

`esp32_devkit_v1_observation_safe.ino` preserves the reviewed, fail-closed
legacy sensor pinout and emits DB2 dual-angle telemetry with continuous 0x92
motor polling. It is retained as a
separate migration candidate; it is not the Behemoth/universal build and is
not installed on the currently connected controllers. See
`SAFETY_ARCHITECTURE.md` before selecting a firmware image.

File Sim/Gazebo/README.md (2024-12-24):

# Dropbear Simulation - Gazebo

Here I'm working on Dropbear's simulation in Gazebo. I wrote a few ROS nodes to handle joint trajectory control, and after some issues, I finally got the closed-loop chain joints working properly in Gazebo. Everything’s smooth now!

### Folder Structure Overview:
- **[`dropbear_detailed_urdf`](./dropbear_detailed_urdf)**: Contains the most granular and detailed simulation of Dropbear. Every part is modeled individually as a mesh, and each part is linked through the URDF using XACRO files. This provides a detailed simulation, allowing for accurate control of individual parts of the robot. This is where I’ll focus moving forward as it gives the most fine-grained control.
  
- **[`dropbear_simplified_urdf`](./dropbear_simplified_urdf)**: Contains a simplified version of the URDF with fewer parts. Here I focus on getting the basic structure of the robot working - Head, Torso, Pelvis, Legs and Hands as their own combined meshes.

- **[`dropbear-sim`](./dropbear-sim)**: Contains my current simulation of Dropbear in Gazebo.

### What's Working:
- ROS nodes for joint trajectory control are set up and running fine.
- Closed-loop chain joints fixed and now working in Gazebo!
  
### What's Next:
- Planning to bring this into Mujoco and Isaac Labs. Some joints like prismatic ones are still having translation issues, but it’s on the todo list.
- I'll experiment with more plugins and extensions to enhance functionality.

### How to Get It Running:

1. Build the project:
   ```bash
   colcon build
   source install/setup.bash
   ```

2. Launch the simulation:
    ```bash
    ros2 launch dropbear dropbear_controllers.launch.py
    ```
    Launches the controller nodes for Dropbear. These nodes manage how the joints of the robot respond to trajectory commands and control signals.

    ```bash
    ros2 launch dropbear dropbear_detailed_gazebo.launch.py
    ```
    Launches the Gazebo simulation environment for Dropbear model.

    ```bash
    ros2 launch dropbear dropbear_detailed_display.launch.py
    ```
    Displays the detailed robot model in Gazebo, including meshes and other visual elements for each part, based on the detailed URDF

    ```bash
    ros2 launch dropbear dropbear_sdf.launch.py
    ```
    Launches the SDF (Simulation Description Format) version of the robot model, providing an alternative to URDF for simulation of closed loop kinematics chain in Gazebo. Has some gazebo tags for certain types of joints, useful especially when dealing with different platforms.

3. Run the trajectory control nodes:
    ```bash
    ros2 run dropbear hand_trajectory_publisher.py
    ```
    Publishes joint trajectory commands for the hands of the robot, controlling how it moves according to user input.

    ```bash
    ros2 run dropbear pelvic_girdle_joints_trajectory_publisher.py
    ```
    Publishes joint trajectory commands for the pelvic girdle joints of the robot, managing the movement of the robot’s lower torso, controlling how it moves - according to user input.

    ```bash
    ros2 run dropbear leg_trajectory_publisher.py
    ```
    Publishes joint trajectory commands for the legs of the robot, controlling how it moves according to user input.

## Video Demo:
Check out the video showing the simulation in action!

Demo Video

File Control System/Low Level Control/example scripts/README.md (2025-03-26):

# HX711 Calibration and SPIFFS Persistence Script

## Overview
This script is designed for the ESP32 to interface with up to four HX711 load cell modules using a shared clock pin and individual data pins. It includes a guided calibration routine and saves the calibration factors to SPIFFS, allowing for persistent calibration across device restarts. The script is integrated into a system that also uses other peripherals, so non-conflicting GPIO pins have been selected.

https://github.com/user-attachments/assets/f911e795-2ed4-4077-9165-cb4e07b29ae3

## Key Features

- **Calibration:**  
  Calibrate any one of the four load cells by applying a known force. The calibration routine guides you through:
  - A baseline (no load) measurement.
  - Two measurements with known forces.
  
  The new calibration factor is computed and saved to SPIFFS.

- **Drift Correction (/drift):**  
  Recalculates the baseline offsets (no-load values) by averaging 50 stable readings for each load cell. This is useful to correct for drift over time.

- **Clear Calibration (/clear):**  
  Deletes the calibration file from SPIFFS and resets all calibration factors to the default (2280.0) and baseline offsets to zero.

- **Transient Spike Filtering:**  
  For each load cell, the last 5 readings are stored in a circular buffer. If a new reading deviates from the average of these 5 samples by more than 500 units, it is replaced with the average, preventing sudden spikes from affecting the output.

---

## Available Commands

- **/calibrate:**  
  Initiates the calibration routine for a selected load cell.  
  _Usage:_ Type `/calibrate` in the Serial Monitor.

- **/drift:**  
  Resets the baseline offsets by averaging 50 stable samples from each load cell to correct for drift.  
  _Usage:_ Type `/drift` in the Serial Monitor.

- **/clear:**  
  Clears the calibration data stored in SPIFFS and resets calibration factors and offsets to default values.  
  _Usage:_ Type `/clear` in the Serial Monitor.

---

### GPIO Pin Table

| GPIO Pin | Peripheral/Module | Description / Usage |
|---|---|---|
| **4** | HX711 SCK (Shared) | Shared clock pin for all HX711 modules. |
| **32** | HX711 DOUT (Load Cell 0) | Data pin for HX711 module connected to Load Cell 0. |
| **12** | HX711 DOUT (Load Cell 1) | Data pin for HX711 module connected to Load Cell 1. |
| **13** | HX711 DOUT (Load Cell 2) | Data pin for HX711 module connected to Load Cell 2. |
| **15** | HX711 DOUT (Load Cell 3) | Data pin for HX711 module connected to Load Cell 3. |
| **5** | MCP_CAN CS | Chip Select for MCP_CAN module over SPI. |
| **17** | MCP_CAN INT | Interrupt pin for MCP_CAN module. |
| **21** | I2C SDA (IMU/Multiplexer) | SDA line for I2C communications with IMU sensors/multiplexer. |
| **22** | I2C SCL (IMU/Multiplexer) | SCL line for I2C communications with IMU sensors/multiplexer. |
| **14** | Analog Input (Outer Calf) | Reads analog sensor data for the outer calf joint. |
| **27** | Analog Input (Inner Calf) | Reads analog sensor data for the inner calf joint. |
| **26** | Analog Input (Hip) | Reads analog sensor data for the hip joint. |
| **25** | Analog Input (Knee) | Reads analog sensor data for the knee joint. |
| **33** | Analog Input (Butt/Hip Roll) | Reads analog sensor data for the butt/hip roll joint. |

---

## Usage Instructions

1. **Upload the Code:**  
   Flash the code to your ESP32 using your preferred IDE.

2. **Open the Serial Monitor:**  
   Set the baud rate to 115200.

3. **Enter Commands:**  
   - Type `/calibrate` to calibrate a load cell.
   - Type `/drift` to reset the baseline (correct drift).
   - Type `/clear` to remove saved calibration data from SPIFFS.

4. **View Output:**  
   The ESP32 continuously prints CSV-formatted weight readings from all four load cells (after calibration, drift correction, and filtering) for monitoring or plotting.

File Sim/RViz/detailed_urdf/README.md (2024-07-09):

# Visualizing Dropbear's URDF in RViz2

Visualizing Dropbear in RViz2 using ROS 2. The package is called `dropbear_urdf`.

## Requirements
- Ubuntu 22.04
- ROS 2 Humble

## Installation and Setup

### 0. Navigate to the preset folder
```sh
cd /Dropbear/Sim/RViz/detailed_urdf
```

### 1. Create and activate a conda envrionment
```sh
conda create --name <ros> --file requirements.txt
conda activate ros
```

### 2. Build the Workspace
Build the project using `colcon`:

```sh
colcon build
```

### 3. Source the Setup File
Source the setup file to overlay the workspace on your environment:

```sh
source install/setup.bash
```

## Launch RViz2

Launch RViz2 visualization by using the provided launch file:

```sh
ros2 launch dropbear_detailed_urdf dropbear_detailed_display.launch.py
```

This will start RViz2 and load the configuration to visualize Dropbear.

## Cole's attempt:

### My partner, Cole is working on a full-blown web-based URDF manipulator app at: https://github.com/robit-man/URDF-Threejs-Modifier. The repositry also contains a version of Dropbear's URDF that you may use to manipulate and simulate Dropbear assembly ❤️

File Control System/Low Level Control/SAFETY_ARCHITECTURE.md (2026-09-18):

# Low-level controller observation and safety architecture

Status: source checkpoint, not a claim about firmware currently installed on
the robot.

## Runtime flow

```mermaid
flowchart LR
  A[Five AS5600 analog outputs] --> B[ESP32 ADC\n10-sample moving average]
  B --> C[Stored side offsets\nwrapped degrees]
  C --> D[50 Hz USB telemetry]
  D --> E[AGX O_RDONLY reader]
  E --> F[Strict legacy5 / DB2 / DB3 parser]
  F --> G[Freshness + side provenance]
  G --> H[Browser software zero]
  H --> I[Corrected USD twin]
  G --> J[Angle CSV recorder]

  K[RMD motor encoder] -. 0x92 response .-> L[MCP2515 CAN RX parser]
  L -. motor-native degrees .-> D
  L -. separately retained .-> J

  M[Browser 3-stage acknowledgement] --> N[Frontend lease]
  N --> O[Physical transport lock]
  O -. always denies .-> P[Actuator command gateway]
```

Solid arrows are active in the host observation stack. RMD `0x92` requests are
non-motion CAN queries and run independently of actuator play. The physical
motion gateway is absent and the frontend endpoint returns
`PHYSICAL_TRANSPORT_LOCKED` after all three clicks.

## Controller gates

| Subsystem | Source state | Success evidence | Failure behavior |
|---|---|---|---|
| External sensors | Runs independently of play mode and CAN | Five degree values at 50 Hz | Host rejects malformed, missing, stale, and out-of-range frames |
| Chirality | Must exist in SPIFFS before CAN initialization | Saved `left` or `right`; reboot follows changes | Missing or invalid chirality leaves CAN disabled |
| MCP2515 initialization | Skipped by the default build | `canReady` only after `CAN_OK` | Sensor telemetry continues after CAN initialization failure |
| Knee mapping | AS5600 drives the upstream actuator shaft 1:1 | Corrected USD closure produces downstream bend | No extra firmware or host knee multiplier |
| Motor-native feedback | Continuous non-motion `0x92` queries | Six verified replies per side in `DB2` or `DB3` | Each missing or stale channel emits `NA`; no AS5600 substitution |
| Legacy motion console | Compile-time false | None in this checkpoint | Motion requests are denied |
| Torque output | Observation-only guard in every sender | Requires a future reviewed gateway and source release | No CAN torque or stop frames from this build |
| Host USB | Continuous readers are `O_RDONLY`; ephemeral writer admits only version/health/observe diagnostics | Fresh sequence plus audited diagnostic byte count | Motion text is rejected before opening a writer; stale sides remain unavailable |

## Dual-angle record

`legacy5` carries five external sensor angles:

```text
outer_calf,inner_calf,hip_pitch,knee_actuator,hip_roll
```

`DB2` carries the same measurements and six independent motor angles:

```text
DB2,millis,outer_ext,inner_ext,hip_pitch_ext,knee_ext,hip_roll_ext,
outer_motor,inner_motor,hip_pitch_motor,knee_motor,hip_yaw_motor,hip_roll_motor
```

`DB3` adds six restart-aligned CAN control angles plus `fresh`, `control`, and
`alignment-fault` bitmasks. It is the preferred record for the dashboard USD.
The five AS5600 channels establish restart alignment and remain independent
cross-checks; ongoing model state comes from the aligned CAN fields.

Angles are degrees. Motor values use `0.01°` RMD multi-turn units. The legacy
RMD-X8 V1.7 reply is a signed 56-bit little-endian value in bytes 1–7; newer
RMD-X10 replies use a signed 32-bit value in bytes 4–7. A missing response is
`NA`. Both layouts retain the documented request ID / response ID offset.

The knee external and motor fields both refer to the upstream actuator shaft.
The downstream knee bend is a kinematic result of the linkage and belongs in
the corrected USD model, not the telemetry decoder.

## Release sequence for motor observation

1. Compile and run the source checks without a controller attached.
2. Verify the RMD model, firmware revision, CAN bitrate, `0x92` request, and
   `request ID + 0x100` response using one unloaded, current-limited actuator.
3. Measure query rate, bus utilization, timeout behavior, and response
   plausibility with motion power unavailable.
4. Correlate each motor angle with its AS5600 through hand-supported travel,
   including wrap, sign, hysteresis, and the knee linkage transform.
5. Review the captured evidence before changing
   `MOTOR_FEEDBACK_QUERY_ALLOWED` or flashing either installed leg controller.

This sequence concerns observation only. It does not release actuator control.

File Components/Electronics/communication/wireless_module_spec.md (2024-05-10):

# Wireless Communication Module

Specs and usage of wireless modules.

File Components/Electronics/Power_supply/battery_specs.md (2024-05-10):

# Battery Specifications

Details on the power systems, especially battery specs.

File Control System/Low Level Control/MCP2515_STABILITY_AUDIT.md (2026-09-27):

# MCP2515 multi-actuator CAN stability audit

Generated: 2026-09-26

Scope: the ESP32 + MCP2515 leg controllers, six MyActuator motors per local
bus, the installed `MCP_CAN_lib` 1.5.1 driver, and the Behemoth observation /
control firmware.

## Executive result

The retry storm was real and was amplified by several firmware defects:

- a timed-out frame could outlive its application transaction and later reads
  could spill into the other MCP2515 transmit mailboxes;
- `MCP_CAN_lib::sendMsg()` treats cleared `TXREQ` as success without checking
  `TXERR`, `MLOA`, or `ABTF`, which reports false success in one-shot mode;
- sticky RX overflow and message-error state was handled with repeated full
  controller resets rather than bounded flag cleanup;
- automatic reads, diagnostics, and output did not have one exclusive RTOS
  transport owner; and
- the library's 8 MHz / 1 Mbit/s preset enables triple sampling (`CNF2=0xC0`),
  even though Microchip documents triple sampling as a slower-bus noise aid.

Firmware `.54` owns only TXB0, validates the wire result, performs all runtime
MCP2515/SPI I/O in one priority-5 CAN task, drains one explicitly flagged RX
mailbox at a time, uses deadline queues and timing counters, and changes the
marginal 8 MHz preset to single sampling
(`CNF1/CNF2/CNF3 = 00/80/80`). It also normalizes the vendor `0xB6/0x92`
active-reply slot before polling and retries a latched-offline address only
once every five seconds so a transiently missed motor can rejoin.

There is also a hardware timing limitation: the current configuration is a
1 Mbit/s bus with an 8 MHz MCP2515 clock. Both the installed library preset
`0x00/0xC0/0x80` and the deployed single-sample override `0x00/0x80/0x80`
produce a 1 TQ Phase Segment 2.
Microchip specifies a minimum valid PS2 of 2 TQ. This timing can appear to work
on a favorable bus but is not datasheet-compliant. Firmware can contain the
failure and expose it; a 16 MHz MCP2515 clock is the direct compliant fix while
retaining the motors' 1 Mbit/s bus rate.

## Evidence and decisions

### 1. Transmit lifetime must be owned by the application

- The MCP2515 has three transmit buffers and two receive buffers.
- `MCP_CAN_lib` 1.5.1 waits at most 2500 microseconds for a free transmit
  buffer, then at most another 2500 microseconds for `TXREQ` to clear.
- `CAN_SENDMSGTIMEOUT` means the driver loaded a mailbox but observed `TXREQ`
  still set at its deadline. It does not prove the frame failed, and it does
  not remove the frame.
- In the installed library, `CAN_GETTXBFTIMEOUT` means all three hardware
  mailboxes were still busy. `.54` instead owns TXB0 exclusively, so a busy
  mailbox is an ownership fault and is aborted before another request.
- One-shot mode limits a message to one actual transmit attempt even after
  arbitration loss or an error frame. Before that first attempt, `TXREQ` can
  remain pending while the controller waits for an available bus.

Decision: only one read transaction may be outstanding and only TXB0 may be
used. A deferred transmit owns that mailbox until either its matching reply
arrives or firmware performs the complete ABAT sequence. Priority motion/STOP
traffic cancels a deferred read before transmission.

### 2. Abort must be a complete sequence

Microchip requires ABAT to be reset after pending `TXREQ` bits clear so that
transmission can continue. The installed library's public `abortTX()` sets
ABAT but does not clear it. Firmware therefore performs the sequence under the
same SPI mutex used by the library:

1. set `CANCTRL.ABAT`;
2. wait a bounded interval for all three `TXBnCTRL.TXREQ` bits to clear;
3. clear `CANCTRL.ABAT`;
4. verify both conditions before allowing another transaction.

The operation aborts all mailboxes. That is acceptable for read-only
observation. During motion it is treated as a bus fault: torque state is
cleared, output authority is disarmed, and three bounded full-leg STOP batches
are attempted. Every motor is attempted in each batch; one absent actuator
cannot starve STOP delivery to the others or create an infinite retry storm.

### 3. Receive rollover was already configured

`MCP_CAN_lib` configures `RXB0CTRL.BUKT` in `MCP_ANY` mode, so RXB0 can roll
over into RXB1. Firmware `.54` no longer separates the library's
`checkReceive()` status read from its `readMsgBuf()` status read: it snapshots
`CANINTF`, reads that exact RX buffer in one burst, and clears only that
buffer's flag. This removed ambiguity in mailbox ownership but did not remove
the physical reply bursts, proving that stale application reads were not the
root cause.

Decision: use the active-low MCP2515 INT output to wake the sole receive task,
drain a bounded batch, and immediately continue when INT remains low. A 1 ms
timeout remains for query scheduling and health work, so a broken/noisy bus
cannot starve the rest of the controller.

### 4. 8 MHz / 1 Mbit timing is outside the valid envelope

For the current preset:

- `TQ = 2 × (BRP + 1) / FOSC = 250 ns`;
- Sync = 1 TQ, PropSeg = 1 TQ, PS1 = 1 TQ, PS2 = 1 TQ;
- total = 4 TQ = 1 microsecond = 1 Mbit/s;
- sample point = 75%;
- PS2 = 1 TQ, while the datasheet requires PS2 >= 2 TQ and describes the
  information-processing time as 2 TQ.

The library preset also sets `SAM=1`, so it samples at the nominal 75% point
and at two preceding half-TQ intervals. Microchip states that three-sample
majority mode was intended for noisy buses at slower rates. `.54` explicitly
enters configuration mode, writes and verifies `0x00/0x80/0x80`, then enters
normal mode. This keeps the 75% sample point but samples once.

The library's 16 MHz / 1 Mbit preset is `0x00/0xCA/0x81`, giving eight TQ and
a valid 2 TQ PS2 at the same nominal rate.

Decision: retain the verified single-sample 8 MHz mode to communicate with the
existing hardware and mark CAN timing health `warn`. For production stability,
fit 16 MHz MCP2515 hardware on both legs and change both initialization and
recovery to a verified 16 MHz profile. Do not switch the oscillator selection
until the physical modules are changed or measured.

## Firmware invariants

- One priority-5 task is the sole runtime MCP2515/SPI transport owner.
- Other tasks submit complete frames by value through a bounded deadline queue;
  motion/STOP enters at the front and the caller receives a correlated result.
- The transport checks `TXERR`, `MLOA`, and `ABTF`; cleared `TXREQ` alone is not
  delivery success.
- TXB0 is the only application transmit mailbox.
- Only one automatic `0x92` read is outstanding.
- `CAN_SENDMSGTIMEOUT` is accepted only for a read transaction and starts a
  bounded deferred-mailbox lifetime.
- Any unconfirmed motion transmit fails closed.
- STOP is three bounded full-leg attempts; all six addresses are attempted even
  when an earlier address fails.
- RX is drained before another automatic motor query.
- Missing-response addresses latch after three misses, then receive one
  isolated retry every five seconds; a valid reply clears the latch.
- Recovery re-enables one-shot mode and clears application transaction state.
- RX overflow flags are cleared after draining instead of triggering a reset;
  TXEP/RXEP alone do not trigger a reset loop.
- Diagnostic serial output never blocks the CAN task and every `DBC1` record is
  bounded below the host's 256-byte admission limit.
- Diagnostics expose EFLG, TEC, REC, mailbox outcomes, queue/wire/batch timing,
  RTOS budget misses, interrupt/wakeup counts, oscillator, and CNF readback.

## 2026-09-26 live validation

Both ESP32s were compiled from source SHA-256
`89ea5e04a36f7f4140d346f716a9f93c48647b99a0dbb3d9c9362fb6ede51f82`
and flashed with application binary SHA-256
`50c17e4ca3392ad46f811f2a58010d9eddc95e56b358b4b29e8984786ca590a6`.
SPIFFS remained at `0x290000` and was not written.

- Both report `behemoth-observation-protocol-2026.09.54` and CNF readback
  `00/80/80`.
- Right: the dashboard reports fresh mask `0x2F` (five motors); only configured
  yaw `0x14C` is absent. After about 16 minutes of uptime, register readback was
  `TEC=0, REC=73`, with no breaker trip. Earlier samples returned to zero, but
  controlled windows also showed REC transiently reaching 115. Seventy-eight
  RX overflows were cleared and reply counts exceed request counts, so this
  remains degraded rather than motion-grade.
- Left: the dashboard reports fresh mask `0x2E` (four configured motors).
  Configured outer calf `0x141` and yaw `0x149` remain absent. The periodic
  retry restored inner calf `0x142` after a transient latch. After about 7.7
  minutes, register readback was `TEC=28, REC=45` with no RX overflow. The left
  poller recorded one TEC circuit-breaker trip during this longer interval;
  live polling was subsequently on and all four responders were fresh.
- The dashboard is enabled and running, both serial streams are fresh and
  complete, and the only reported unobserved joints are `left_outer_calf`,
  `left_hip_yaw`, and `right_hip_yaw`.
- Confirmed `0xB6,0x92,0` delivery did not remove right `0x148` reply bursts;
  a passive two-second sniff was quiet. Atomic RX-buffer ownership also did not
  remove them. This rules out a continuously enabled active-reply stream and a
  stale library mailbox as root causes, leaving the out-of-spec timing/ACK path
  as the limiting condition.
- No torque, position, enable, or other motion command was sent during these
  tests.

This run does not pass the five-minute motion-readiness gate: the right bus has
transient receive warnings and cleared overflows, the left poller has tripped
its TEC breaker once, and both yaw controllers are still silent at their
configured IDs. `.54` is accepted for read-only diagnostics and dashboard
observation only.

## Read-only acceptance gate

For each leg, over a minimum five-minute observation window:

1. exact expected firmware version and `one_shot_tx=true`;
2. no serial-record corruption during recovery;
3. no persistent `TXREQ` ownership and zero abort failures;
4. no growth in RX0OVR/RX1OVR after startup;
5. TEC/REC return to and remain near zero on a healthy bus;
6. no repeated five-second recovery loop;
7. each physically present motor has repeatable replies at its actual address;
8. missing configured addresses back off without starving responding motors;
9. play remains false and no motion opcode is sent during this gate.

Passing this gate validates the software containment. It does not make the
8 MHz / 1 Mbit timing profile compliant.

## Primary sources

- Microchip, *MCP2515 Family Data Sheet*, DS20001801K:
  https://ww1.microchip.com/downloads/en/DeviceDoc/MCP2515-Family-Data-Sheet-DS20001801K.pdf
- Microchip, *An In-depth Look at the MCP2510* (AN739), including the guidance
  that triple sampling is intended for noisy, slower buses:
  https://ww1.microchip.com/downloads/en/Appnotes/00739a.pdf
- Cory J. Fowler, official `MCP_CAN_lib` source and 1.5.1 release:
  https://github.com/coryjfowler/MCP_CAN_lib/blob/master/mcp_can.cpp
  and https://github.com/coryjfowler/MCP_CAN_lib/releases/tag/1.5.1
- MYACTUATOR, official RMD-X downloads and current protocol/manual index:
  https://www.myactuator.com/downloads-xseries

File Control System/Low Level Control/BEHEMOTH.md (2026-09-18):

# Dropbear Universal ESP32 Firmware

Unified low-level firmware for the Dropbear robot's ESP32-class subsystem controllers.

This single Arduino sketch is designed to be flashed onto multiple Dropbear ESP32 controllers and then configured, through SPIFFS, USB Serial, or the captive setup portal, to become one of several **mutually exclusive hardware personalities**.

The firmware currently supports:

```text
DROPBEAR UNIVERSAL ESP32 FIRMWARE
│
├── LEFTLEG
│   ├── Standalone / original Dropbear control
│   └── HyperSpawn / ROS2 CAN route
│
├── RIGHTLEG
│   ├── Standalone / original Dropbear control
│   └── HyperSpawn / ROS2 CAN route
│
├── CENTER
│   └── TCA9548A + five-IMU polling stack
│
└── HEADNECK
    └── six-axis A4988 / FastAccelStepper neck controller
```

All personalities share the same:

- SPIFFS configuration system,
- role-aware Wi-Fi captive portal,
- DB1 addressed command router,
- USB Serial transport,
- structured logging,
- diagnostics framework,
- configuration UI,
- reboot/topology semantics,
- safety-oriented command routing.

The role-specific hardware graphs are **never initialized simultaneously**.

> **Important:** `LEFTLEG`, `RIGHTLEG`, `CENTER`, and `HEADNECK` use overlapping GPIOs. Changing hardware role is a reboot-bound topology change. Never treat role selection as a live GPIO-mode switch.

The firmware file documented by this README is:

```text
firmware_full_libs_neck.ino
```

Build and inspect this source through the
[`dropbear_control` connected-device dashboard](https://github.com/robit-man/dropbear_control).
The dashboard pins Arduino ESP32 core 2.0.13, FastAccelStepper 0.30.15, and
MCP_CAN_lib 1.5.1, then verifies the exact source before an upload can be
selected.

## SPIFFS-preserving uploads

`partitions.csv` keeps SPIFFS at the Arduino default location, `0x290000`, and
retains its original `0x160000` extent. It combines the two old OTA application
slots into one `0x280000` factory application region so Behemoth fits without
moving saved role, chirality, calibration, limits, Wi-Fi, or controller
settings.

The dashboard explicitly selects `EraseFlash=none`. Immediately before an
upload, it reads only the connected ESP32 partition table and requires the
installed SPIFFS offset and size to match. A different or unreadable partition
layout blocks the flash so settings cannot be silently stranded. This process
does not erase or rewrite SPIFFS; it updates the application and partition
table while preserving the settings bytes in place.

## USB angle telemetry

After an addressed `observe on`, leg roles emit a versioned `DB3` line at 50 Hz:

```text
DB3,<controller_ms>,<five AS5600 degrees>,<six raw RMD degrees>,<six AS5600-aligned RMD control degrees>,<fresh mask>,<control mask>,<alignment-fault mask>
```

Every angle is in degrees. The five AS5600 fields remain independent absolute
measurements. The six motor fields come from read-only RMD V1.7/V4.2 `0x92`
multi-turn-angle replies at `0.01°` per least-significant bit; a missing or
stale reply is emitted as `NA`, never replaced with an AS5600 value. Hip yaw has
no dedicated AS5600; its aligned field is boot-relative to the first verified
motor reply.

The knee motor field is the upstream actuator-shaft angle at 1:1 scale. The
mechanical linkage or digital twin is responsible for deriving the larger
downstream knee motion from that shaft angle.

At every restart, each of the five externally sensed axes collects eight
matching AS5600/CAN samples. That establishes a fixed offset from the RMD
multi-turn angle into the calibrated joint coordinate. Fresh CAN-native angle
then supplies continuous position feedback; the AS5600 remains available in
telemetry and as an independent drift check. CAN feedback is never silently
replaced by AS5600 during control. A stale CAN value produces zero impedance
torque, and three consecutive disagreements above 12 degrees latch an alignment
fault until restart. Hip yaw remains motor telemetry only because it has no
external absolute reference.

The serial identity and health records are:

```text
DBV1,<role>,<firmware>,DB1,DB3,<capability;list>
DBH1,<role>,<ms>,<overall>,<runtime>,<can>,<sensor_mask>,<motor_fresh_mask>,<motor_control_mask>,<alignment_fault_mask>,<queries>,<responses>,<query_failures>,<malformed>,<can_failures>
```

Use `<DB1:LEFTLEG> version`, `<DB1:RIGHTLEG> health`, and the corresponding
addressed `observe on|off` commands. `GET /api/version` exposes the same
contract through the captive portal.

---

# Contents

1. [System overview](#1-system-overview)
2. [Why one universal firmware](#2-why-one-universal-firmware)
3. [Boot-time hardware personalities](#3-boot-time-hardware-personalities)
4. [Control routes](#4-control-routes)
5. [DB1 addressed command protocol](#5-db1-addressed-command-protocol)
6. [Target validation and authority](#6-target-validation-and-authority)
7. [First boot and DROPBEAR-SETUP](#7-first-boot-and-dropbear-setup)
8. [Wi-Fi identities](#8-wi-fi-identities)
9. [Common runtime architecture](#9-common-runtime-architecture)
10. [LEFTLEG / RIGHTLEG hardware](#10-leftleg--rightleg-hardware)
11. [AS5600 PWM joint sensing](#11-as5600-pwm-joint-sensing)
12. [Leg actuator map](#12-leg-actuator-map)
13. [Leg Standalone route](#13-leg-standalone-route)
14. [Leg impedance control](#14-leg-impedance-control)
15. [HyperSpawn / ROS2 route](#15-hyperspawn--ros2-route)
16. [HyperSpawn CAN protocol](#16-hyperspawn-can-protocol)
17. [HyperSpawn watchdog and command commit](#17-hyperspawn-watchdog-and-command-commit)
18. [CENTER hardware personality](#18-center-hardware-personality)
19. [TCA9548A / IMU stack](#19-tca9548a--imu-stack)
20. [HEADNECK hardware personality](#20-headneck-hardware-personality)
21. [HEADNECK motion model](#21-headneck-motion-model)
22. [HEADNECK command grammar](#22-headneck-command-grammar)
23. [HEADNECK homing](#23-headneck-homing)
24. [HEADNECK diagnostics and feedback limitations](#24-headneck-diagnostics-and-feedback-limitations)
25. [Captive portal](#25-captive-portal)
26. [Portal API](#26-portal-api)
27. [Diagnostics system](#27-diagnostics-system)
28. [SPIFFS configuration](#28-spiffs-configuration)
29. [Serial command reference](#29-serial-command-reference)
30. [Safety behavior](#30-safety-behavior)
31. [Commissioning](#31-commissioning)
32. [Dependencies](#32-dependencies)
33. [Known limitations](#33-known-limitations)
34. [Repository relationships](#34-repository-relationships)

---

# 1. System overview

The firmware separates **hardware identity**, **control authority**, and **command transport**.

```text
                         INCOMING TRANSPORT
             ┌──────────────┼───────────────┐
             │              │               │
          USB Serial    Captive Portal   Neck Bluetooth
             │              │               │
             └──────────────┼───────────────┘
                            │
                            ▼
                     DB1 ROUTER
                            │
                 target identity check
                            │
                            ▼
                    authority check
                            │
                            ▼
                    role-specific parser
                            │
          ┌─────────────────┼────────────────────┐
          ▼                 ▼                    ▼
     LEFT/RIGHT LEG       CENTER             HEADNECK
          │                 │                    │
          ▼                 ▼                    ▼
    leg controller        IMU stack         stepper stack
```

For leg roles, there is an additional control-route selector:

```text
LEFTLEG / RIGHTLEG
       │
       ├── STANDALONE
       │      └── Portal / Serial owns normal motion
       │
       └── HYPERSPAWN
              └── ROS2 / CAN owns normal motion
```

The underlying actuator/sensor/safety layer remains common.

---

# 2. Why one universal firmware

The goal is to eliminate firmware ambiguity between physical robot subsystems.

A blank ESP32 can be flashed with the same image, expose:

```text
DROPBEAR-SETUP
```

and then be configured as:

```text
LEFTLEG
RIGHTLEG
CENTER
HEADNECK
```

After reboot, it becomes that subsystem.

This has several benefits:

- one firmware artifact to version,
- one configuration format,
- one captive portal framework,
- one diagnostics format,
- one command-addressing protocol,
- one logging model,
- clear hardware-role identity,
- less risk of flashing the wrong source tree onto a physical controller.

This does **not** mean the hardware drivers are shared blindly.

The firmware intentionally uses role-gated initialization because the physical pin graphs overlap.

---

# 3. Boot-time hardware personalities

The internal hardware identity is effectively:

```text
DeviceRole
```

with current values:

```text
UNCONFIGURED
LEFTLEG
RIGHTLEG
CENTER
HEADNECK
```

Reserved DB1 targets also exist for:

```text
LEFTARM
RIGHTARM
```

but arm control is not implemented by this firmware.

An arm-targeted command therefore returns a role-unsupported error rather than falling through into another parser.

## Role switching

Role changes are persistent configuration changes.

Examples:

```text
<DB1:LEFTLEG> role right
<DB1:HEADNECK> role left
<DB1:SETUP> role head
```

A physical-role change should always be followed by reboot.

The firmware marks topology-sensitive changes as:

```text
REBOOT_REQUIRED
```

and disables active runtime state where appropriate.

---

# 4. Control routes

Only leg personalities have a secondary operating-route selection.

Persisted values:

```text
OperatingMode:standalone
```

or:

```text
OperatingMode:hyperspawn
```

Default:

```text
standalone
```

Older configurations that do not contain `OperatingMode:` are treated as Standalone.

## Standalone

Normal motion authority comes from:

```text
USB Serial
Captive portal
```

Features:

- direct torque,
- local impedance,
- calibration,
- manual diagnostics,
- local configuration.

## HyperSpawn

Normal motion authority comes from targeted CAN commands.

Features:

- six-joint position route,
- six-joint torque route,
- atomic two-frame command commit,
- 500 Hz state frames,
- 1 Hz heartbeat,
- command watchdog,
- optional compatibility with upstream legacy brain-origin frames.

Portal and Serial remain available for:

- diagnostics,
- `stop`,
- `zero`,
- configuration,
- route changes,
- SPIFFS access,
- reboot.

Normal local torque/impedance commands are rejected in HyperSpawn mode.

---

# 5. DB1 addressed command protocol

The universal firmware uses an explicit destination envelope:

```text
<DB1:TARGET> payload
```

Examples:

```text
<DB1:LEFTLEG> torque knee 25
<DB1:RIGHTLEG> impedance knee 1 180 0
<DB1:HEADNECK> X10,Y-5,Z15,H30,S1.5,A2,R10,P-5
<DB1:CENTER> status
<DB1:SETUP> role left
```

Recognized targets:

```text
SETUP
LEFTLEG
RIGHTLEG
CENTER
HEADNECK
LEFTARM
RIGHTARM
ALL
```

Aliases recognized by the parser include forms such as:

```text
LEFT_LEG
RIGHT_LEG
HEAD_NECK
HEAD
NECK
```

## Why DB1 exists

The header prevents a command intended for one robot appendage from being executed by another controller.

Example:

```text
RX:
<DB1:LEFTLEG> torque knee 50

actual controller:
RIGHTLEG
```

Result:

```text
ERR|TARGET_MISMATCH|expected=RIGHTLEG|received=LEFTLEG
```

The torque parser is never entered.

## Missing header

Unaddressed commands are rejected by default:

```text
ERR|MISSING_TARGET_HEADER|...
```

SPIFFS contains:

```text
LegacyUnaddressedCommands:0
```

This can be deliberately enabled for migration, but should normally remain off.

## Broadcast

The only permitted broadcast payload is:

```text
<DB1:ALL> stop
```

Motion-producing broadcast commands are rejected.

This means the firmware explicitly forbids patterns such as:

```text
<DB1:ALL> torque knee 100
<DB1:ALL> HOME
<DB1:ALL> play
```

---

# 6. Target validation and authority

A command must pass multiple checks before execution:

```text
raw command
    │
    ▼
DB1 envelope valid?
    │
    ▼
target matches this ESP?
    │
    ▼
target role implemented?
    │
    ▼
source permitted?
    │
    ▼
current operating route permits this command?
    │
    ▼
runtime/safety state permits it?
    │
    ▼
role-specific parser
```

This produces two different classes of protection.

## Target protection

Example:

```text
LEFTLEG command received by RIGHTLEG
```

is rejected as a destination mismatch.

## Authority protection

Example:

```text
<DB1:LEFTLEG> torque knee 40
```

sent over USB while the left leg is in:

```text
OperatingMode:hyperspawn
```

passes the target check but fails motion-authority policy.

The HyperSpawn route owns normal motion.

`stop` remains available as a safety action.

---

# 7. First boot and DROPBEAR-SETUP

If:

```text
/config.txt
```

does not exist or does not contain a valid role, the controller starts unconfigured.

Wi-Fi:

```text
DROPBEAR-SETUP
```

DB1 identity:

```text
SETUP
```

Example first-boot command:

```text
<DB1:SETUP> role left
```

or use the captive configurator.

During unconfigured boot, the firmware intentionally avoids starting the physical motor/IMU topology.

This prevents a blank board from guessing which GPIO graph is connected.

---

# 8. Wi-Fi identities

The SoftAP SSID is derived from the persisted hardware identity.

| Role | SSID |
| --- | --- |
| Unconfigured | `DROPBEAR-SETUP` |
| Left leg | `LEFTLEG` |
| Right leg | `RIGHTLEG` |
| Center | `CENTER` |
| Head / neck  | `HEADNECK` |

There is no separate arbitrary SSID setting.

Changing role and rebooting automatically changes the network identity.

Example:

```text
LEFTLEG
  ↓ role right
reboot
  ↓
RIGHTLEG
```

Default captive-portal address:

```text
192.168.4.1
```

The SoftAP is currently open and should be treated as a development/local robot network.

---

# 9. Common runtime architecture

The universal firmware shares the following infrastructure:

```text
SPIFFS
Wi-Fi SoftAP
wildcard DNS
WebServer
DB1 command routing
FreeRTOS synchronization
command logging
configuration persistence
diagnostic snapshots
reboot management
```

Role-specific runtime state is separate.

Conceptually:

```text
setup()
  │
  ├── Serial
  ├── mutexes / queues
  ├── SPIFFS
  ├── load configuration
  ├── determine DeviceRole
  ├── start portal
  │
  └── role switch
       ├── initLegHardware()
       ├── initCenterHardware()
       └── setupNeckHardware()
```

The role-specific GPIO graph is not supposed to leak into another personality.

---

# 10. LEFTLEG / RIGHTLEG hardware

## MCP2515 SPI

| Signal | GPIO |
| --- | ---: |
| CS |  `5` |
| INT | `17` |
| SCK | `18` |
| MISO | `19` |
| MOSI | `23` |

Initialization:

```cpp
SPI.begin(18, 19, 23, 5);
```

CAN configuration:

```text
1,000,000 bit/s
8 MHz MCP2515 crystal
normal mode
11-bit CAN identifiers
```

## External joint sensors

The original physical leg wiring is preserved:

| Joint | GPIO |
| --- | ---: |
| Outer calf | `14` |
| Inner calf | `27` |
| Hip pitch  | `26` |
| Knee | `25` |
| Hip roll | `33` |

There is no sixth external hip-yaw AS5600 in the current leg mapping.

---

# 11. AS5600 PWM joint sensing

The universal Wi-Fi build treats each AS5600 OUT signal as a one-wire PWM signal.

The firmware no longer uses `analogRead()` for these five channels.

This is important because on a classic ESP32:

```text
GPIO14
GPIO27
GPIO26
GPIO25
```

belong to ADC2, which conflicts with continuous Wi-Fi operation.

The PWM path avoids that conflict while preserving the existing physical GPIO harness.

## Acquisition

Each pin uses a `CHANGE` interrupt.

The capture tracks:

```text
last rising edge
high duration
period
last edge
frame count
valid state
```

Accepted period window:

```text
800 us .. 12,000 us
```

Signal stale threshold:

```text
100 ms
```

The PWM decoding maps approximately:

```text
2.94% duty -> 0°
97.06% duty -> 360°
```

using:

```text
128 / 4351
4223 / 4351
```

as the useful duty endpoints.

## Compatibility representation

The decoded angle is converted back into a pseudo ADC-style value:

```text
0 .. 4095
```

This allows the existing moving-average, offset, and calibration architecture to remain compatible.

## Sensor processing

Nominal processing period:

```text
1 ms
```

or about:

```text
1000 Hz
```

The firmware retains the ten-sample moving-average layer.

---

# 12. Leg actuator map

The original MyActuator CAN IDs are retained.

| Internal index | Side  | Joint |  CAN ID |
| ---: | ----- | --- | ---: |
| 0 | Right | Outer calf | `0x144` |
| 1 | Left  | Outer calf | `0x141` |
| 2 | Right | Inner calf | `0x143` |
| 3 | Left  | Inner calf | `0x142` |
| 4 | Right | Knee | `0x148` |
| 5 | Left  | Knee | `0x145` |
| 6 | Right | Hip pitch  | `0x147` |
| 7 | Left  | Hip pitch  | `0x146` |
| 8 | Right | Hip yaw | `0x14C` |
| 9 | Left  | Hip yaw | `0x149` |
| 10 | Right | Hip roll | `0x14B` |
| 11 | Left  | Hip roll | `0x14A` |

The array is intentionally interleaved:

```text
even index = right
odd index  = left
```

A LEFTLEG controller transmits only to:

```text
0x141
0x142
0x145
0x146
0x149
0x14A
```

A RIGHTLEG controller transmits only to:

```text
0x144
0x143
0x148
0x147
0x14C
0x14B
```

---

# 13. Leg Standalone route

Standalone is the default leg-control structure.

Example direct torque:

```text
<DB1:LEFTLEG> torque knee 25
```

Canonical grammar:

```text
<DB1:LEFTLEG|RIGHTLEG> torque <appendage> <torqueValue>
```

Supported appendages:

```text
outer_calf
inner_calf
knee
hip_pitch
hip_yaw
hip_roll
```

The DB1 target determines the leg.

Legacy payloads containing `left` or `right` inside the payload are tolerated only after the outer DB1 destination has already been validated.

## MyActuator output

Normal actuator command:

```text
0xA1
```

Stop command:

```text
0x81
```

The firmware uses one normal periodic CAN writer.

Command parsers update state/setpoints rather than creating independent competing actuator TX loops.

---

# 14. Leg impedance control

Canonical command:

```text
<DB1:LEFTLEG> impedance knee 1 180 0
```

Grammar:

```text
impedance <appendage> <0|1> <desiredPosition> <desiredVelocity>
```

Supported impedance joints:

```text
outer_calf
inner_calf
knee
hip_pitch
hip_roll
```

Hip yaw remains direct-torque only because no external hip-yaw AS5600 is currently mapped.

Conceptual controller:

```text
τ =
    K(q* - q)
  + D(dq* - dq)
  + M(ddq)
```

The resulting value passes through:

```text
direction multiplier
joint constraint behavior
global torque clamp
single CAN-output task
```

before becoming an actuator command.

---

# 15. HyperSpawn / ROS2 route

The HyperSpawn route is the alternative operating structure for LEFTLEG and RIGHTLEG.

Select:

```text
<DB1:LEFTLEG> mode hyperspawn
```

or use the portal.

The change is persisted and treated as reboot-bound.

## Identity

Left leg:

```text
node ID 0x12
limb ID 2
```

Right leg:

```text
node ID 0x13
limb ID 3
```

## Control behavior

### Position command

```text
ROS/CAN position target
        │
        ▼
wire units -> degrees
        │
        ▼
AS5600 restart zero + continuous RMD 0x92 feedback
        │
        ▼
local impedance controller
        │
        ▼
A1 torque
```

### Torque command

```text
ROS/CAN torque
        │
        ▼
HyperSpawn torque bank
        │
        ▼
common safety layer
        │
        ▼
A1 torque
```

This fills the low-level control gap in the higher-level `dropbear_firmware` architecture without abandoning the physical Dropbear actuator/sensor implementation.

---

# 16. HyperSpawn CAN protocol

Message type layout:

```text
CAN ID = (node_id << 4) | message_type
```

Core message types:

```text
0x00 heartbeat
0x01 position base
0x02 torque base
0x03 state base
0x04 position extension
0x05 torque extension
0x06 state extension
0x0F fault
```

## LEFTLEG

|  CAN ID | Meaning |
| ---: | --- |
| `0x120` | Heartbeat |
| `0x121` | Position joints 0..3 |
| `0x122` | Torque joints 0..3 |
| `0x123` | State joints 0..3 |
| `0x124` | Position joints 4..5 |
| `0x125` | Torque joints 4..5 |
| `0x126` | State joints 4..5 |
| `0x12F` | Fault |

## RIGHTLEG

|  CAN ID | Meaning |
| ---: | --- |
| `0x130` | Heartbeat |
| `0x131` | Position joints 0..3 |
| `0x132` | Torque joints 0..3 |
| `0x133` | State joints 0..3 |
| `0x134` | Position joints 4..5 |
| `0x135` | Torque joints 4..5 |
| `0x136` | State joints 4..5 |
| `0x13F` | Fault |

## Six-joint wire order

```text
0 hip_pitch
1 hip_roll
2 hip_yaw
3 knee
4 outer_calf
5 inner_calf
```

Each joint value is a signed 16-bit value encoded big-endian.

## Legacy compatibility

Optional:

```text
HyperspawnLegacyBroadcast:1
```

accepts the earlier brain-origin style such as:

```text
0x011
0x012
```

This is off by default because such frames do not uniquely distinguish left and right limbs on a shared bus.

---

# 17. HyperSpawn watchdog and command commit

## Atomic command commit

A six-joint targeted command requires both frames.

Position:

```text
base 0x121/0x131
extension 0x124/0x134
```

Torque:

```text
base 0x122/0x132
extension 0x125/0x135
```

The firmware stages the fragments and commits all six joint values together.

Fragment timeout:

```text
50 ms
```

A partial command is discarded rather than exposing the control loop to a mixture of old and new trajectory values.

## Command watchdog

Default:

```text
250 ms
```

Persisted:

```text
HyperspawnCommandTimeoutMs:250
```

Valid configured range:

```text
50 .. 10000 ms
```

If the active HyperSpawn control stream goes stale:

```text
control mode -> NONE
pending fragments -> cleared
HyperSpawn torque bank -> zero
stop burst -> queued
fault -> transmitted
```

## Auto-arm

Default:

```text
HyperspawnAutoArm:1
```

With auto-arm enabled, a complete valid command can arm the leg.

Without auto-arm, use:

```text
<DB1:LEFTLEG> play
```

after the route is ready.

## Position scale

Persisted:

```text
HyperspawnPositionUnitsPerDegree:1.0
```

This provides an explicit conversion boundary because the upstream architecture does not establish a final physical unit contract for the raw `int16_t` position field.

---

# 18. CENTER hardware personality

CENTER is a completely different hardware stack.

It does not initialize:

```text
leg MCP2515 control
AS5600 leg sensing
neck FastAccelStepper stack
```

Instead it initializes the shared I²C bus and IMU multiplexer stack.

SSID:

```text
CENTER
```

DB1 identity:

```text
CENTER
```

Example:

```text
<DB1:CENTER> status
```

---

# 19. TCA9548A / IMU stack

I²C:

| Signal | GPIO |
| --- | ---: |
| SDA | `21` |
| SCL | `22` |

Current mux:

```text
TCA9548A @ 0x70
```

Current IMU address:

```text
0x68
```

Channels:

```text
0
1
2
3
4
```

Topology:

```text
ESP32
  │
  ├── SDA21
  └── SCL22
       │
       ▼
    TCA9548A 0x70
       │
       ├── CH0 -> IMU0 @ 0x68
       ├── CH1 -> IMU1 @ 0x68
       ├── CH2 -> IMU2 @ 0x68
       ├── CH3 -> IMU3 @ 0x68
       └── CH4 -> IMU4 @ 0x68
```

The firmware selects a mux channel before reading its IMU.

Current raw read begins at register:

```text
0x3B
```

and consumes 14 bytes for accelerometer, temperature field, and gyroscope layout.

The current firmware reports raw accelerometer and gyroscope state. It does not yet perform full orientation fusion.

---

# 20. HEADNECK hardware personality

HEADNECK is a fourth mutually exclusive physical controller stack.

It uses:

```text
FastAccelStepper
6 × A4988-style STEP/DIR channels
optional shared enable pin
optional Bluetooth Classic
```

SSID:

```text
HEADNECK
```

DB1 target:

```text
HEADNECK
```

Bluetooth name:

```text
NECK_BT
```

when enabled.

## Pinout

| Motor | STEP |  DIR |
| ----- | ---: | ---: |
| M1 | `33` | `32` |
| M2 | `18` | `26` |
| M3 | `23` | `14` |
| M4 | `19` | `27` |
| M5 | `22` | `12` |
| M6 | `21` | `13` |

Optional shared enable:

```text
GPIO25
```

## Why HEADNECK must be boot-exclusive

These pins overlap heavily with leg and center roles.

Examples:

```text
GPIO18
leg    -> MCP2515 SCK
neck   -> M2 STEP

GPIO23
leg    -> MCP2515 MOSI
neck   -> M3 STEP

GPIO21
center -> I²C SDA
neck   -> M6 STEP

GPIO22
center -> I²C SCL
neck   -> M5 STEP

GPIO14
leg    -> outer-calf AS5600
neck   -> M3 DIR
```

Therefore HEADNECK must never initialize leg or center peripherals during the same boot.

---

# 21. HEADNECK motion model

Defaults:

```text
speed              48,000 steps/s
acceleration       36,000 steps/s²
steps/mm           426.67
per-motor min      0 mm
per-motor max      80 mm
```

Persisted fields allow these values to be adjusted.

The controller tracks:

```text
current FastAccelStepper library position
target step position
target mm
running/not running
software homed state
homing state
motion armed state
```

## Direct actuator movement

A direct command specifies actuator extension in millimeters.

Example:

```text
<DB1:HEADNECK> 1:30,2:45,3:20
```

Conversion:

```text
steps = mm × NeckStepsPerMm
```

Then per-actuator software min/max limits are applied.

## Pose movement

Example:

```text
<DB1:HEADNECK> X10,Y-5,Z15,H30,S1.5,A2,R10,P-5
```

Fields:

```text
X
Y
Z
H  height
S  speed multiplier
A  acceleration multiplier
R  roll contribution
P  pitch contribution
```

The current Stewart-style mapping produces six step targets from the pose fields.

The firmware retains the original pose-level clamp equivalent to:

```text
0 .. 80 mm
```

using a pose conversion scale of:

```text
400 steps/mm
```

and then applies the separately configurable per-actuator bounds as a second limit layer.

## Quaternion command

Grammar:

```text
Q:w,x,y,z[,Hn][,Sn][,An]
```

Example:

```text
<DB1:HEADNECK> Q:1,0,0,0,H20,S1,A1
```

The quaternion is normalized and converted to Euler yaw/pitch/roll before being passed into the neck pose controller.

A zero-norm quaternion is rejected.

---

# 22. HEADNECK command grammar

All commands should carry:

```text
<DB1:HEADNECK>
```

unless legacy unaddressed commands have deliberately been enabled.

## Direct motor target

```text
<DB1:HEADNECK> 1:30
<DB1:HEADNECK> 1:30,2:45,3:20
```

Values are millimeters.

## Pose

```text
<DB1:HEADNECK> X10,Y-5,Z15,H30,S1.5,A2,R10,P-5
```

## Quaternion

```text
<DB1:HEADNECK> Q:1,0,0,0,H20,S1,A1
```

## Compound commands

The neck parser supports `|` chained commands.

Example:

```text
<DB1:HEADNECK> 1:20,2:20|3:35,4:35
```

Segments are processed sequentially by the neck parser.

## Health

```text
<DB1:HEADNECK> HEALTH
```

or uppercase compatibility:

```text
<DB1:HEADNECK> STATUS
```

returns the neck health/state string.

The universal lowercase:

```text
<DB1:HEADNECK> status
```

is handled by the common universal status path.

## Motion controls

```text
<DB1:HEADNECK> play
<DB1:HEADNECK> stop
<DB1:HEADNECK> zero
```

Neck-specific equivalents:

```text
<DB1:HEADNECK> neck stop
<DB1:HEADNECK> neck zero
<DB1:HEADNECK> neck status
```

## Speed

```text
<DB1:HEADNECK> neck speed 48000
```

Valid firmware range:

```text
1 .. 200000 Hz
```

## Acceleration

```text
<DB1:HEADNECK> neck accel 36000
```

Valid firmware range:

```text
1 .. 2000000 steps/s²
```

## Bluetooth

```text
<DB1:HEADNECK> neck bluetooth on
<DB1:HEADNECK> neck bluetooth off
```

A Bluetooth topology change requires reboot.

## Boot auto-home

```text
<DB1:HEADNECK> neck autohome on
<DB1:HEADNECK> neck autohome off
```

Unified-firmware default:

```text
OFF
```

This is intentionally safer than automatically driving the mechanism on every boot.

## Per-motor limits

```text
<DB1:HEADNECK> neck limits 1 0 80
```

Grammar:

```text
neck limits <motor 1..6> <min_mm> <max_mm>
```

---

# 23. HEADNECK homing

The firmware preserves two open-loop homing styles.

Commands:

```text
<DB1:HEADNECK> HOME
<DB1:HEADNECK> HOME_BRUTE
<DB1:HEADNECK> HOME_SOFT
```

`HOME` is an alias for brute home.

## Soft home

Current sequence:

```text
height target          -40
speed multiplier       2.0
accel multiplier       2.0
settle                 2200 ms
```

After the settle period:

```text
stepper motion stopped
current library positions -> 0
software homed -> true
```

## Brute home

Preparation phase:

```text
height target          -55
speed multiplier       2.5
accel multiplier       2.5
settle                 2300 ms
```

Then:

```text
150 ms transition gap
```

Final overtravel phase:

```text
height target          -80
speed multiplier       3.0
accel multiplier       3.0
settle                 2600 ms
```

Then software zero is established.

## Critical homing limitation

Current neck homing is:

```text
OPEN LOOP OVERTRAVEL + SOFTWARE ZERO
```

It does **not** verify physical contact using:

- a limit switch,
- an encoder,
- current sensing,
- force sensing,
- a homing sensor.

The homing routine intentionally bypasses ordinary software travel clamps.

Treat it as a mechanical procedure, not as a measured reference acquisition.

---

# 24. HEADNECK diagnostics and feedback limitations

The neck controller currently has no physical actuator-position feedback.

The firmware knows:

```text
what step position FastAccelStepper believes it is at
what target it was commanded to
whether the library reports motion
```

It does not know with certainty:

```text
whether a step was missed
whether the leadscrew stalled
whether a coupling slipped
whether the platform physically reached the target
```

Therefore the portal explicitly treats neck state as:

```text
FEEDBACK=OPEN_LOOP
```

A typical motor diagnostic should be interpreted as:

```text
M3
STEP GPIO          23
DIR GPIO           14
current library    14,200 steps
current derived    33.28 mm
target             14,500 steps
target derived     33.98 mm
running            yes
feedback           OPEN_LOOP
```

Do not interpret `current library position` as independently measured physical extension.

---

# 25. Captive portal

The portal provides a role-aware local interface.

It uses:

- ESP32 SoftAP,
- wildcard DNS,
- captive-check redirects,
- `WebServer`,
- SPIFFS-backed configuration,
- client-side role-specific presentation.

Common portal functions include:

```text
live system state
configuration
diagnostics
terminal / command log
SPIFFS browser
raw config editor
reboot
```

Leg and neck motion is locked after every boot and every SoftAP restart. The
portal requires three ordered acknowledgements:

1. the robot is mechanically supported;
2. the E-stop and power disconnect are ready; and
3. the operator types `ENABLE LEFTLEG`, `ENABLE RIGHTLEG`, or
   `ENABLE HEADNECK`, matching the controller's DB1 identity.

The resulting web-motion lease lasts 90 seconds. Expiry clears torque
setpoints, disables play, and queues a three-frame stop burst. `STOP` and the
dedicated **LOCK + STOP NOW** control remain available without an unlock.
Ingress and command-queue execution both enforce the lease; hiding or
reenabling a disabled browser button cannot bypass it.

Role-specific panels are shown for:

```text
leg control / AS5600 / CAN
HyperSpawn route
center IMUs
head/neck pose and motor state
```

## Portal command addressing

The browser automatically creates the DB1 envelope.

For example, pressing a knee torque control while connected to LEFTLEG internally produces:

```text
<DB1:LEFTLEG> torque knee 40
```

The target identity is still validated by the backend.

The portal does not bypass DB1.

## Bounded leg motor test

Each of the six selected-leg rows includes a 250 ms torque-pulse test. The
firmware accepts pulse commands only in standalone leg mode, only while the
portal motion lease is active, and only when fresh RMD `0x92` motor angle
feedback exists. The five AS5600-equipped axes must also have completed their
boot alignment without an alignment fault. Hip yaw uses its fresh motor-native
angle because it has no external AS5600.

The pulse command is bounded to `-25..25` firmware torque units and
`50..500 ms`. During the pulse, every other motor owned by that ESP32 receives
zero. Completion sends zero to all six motors and queues a stop burst.

---

# 26. Portal API

Current endpoints:

```text
GET  /
GET  /api/state
GET  /api/diagnostics

GET  /api/config
POST /api/config
POST /api/config/reload
POST /api/config/raw

POST /api/command
POST /api/safety/advance
POST /api/safety/lock
GET  /api/log

GET  /api/spiffs/list
GET  /api/spiffs/read

POST /api/calibrate/sensors
POST /api/reboot
```

Captive-check routes include common Android, Apple, and Windows endpoints.

State-changing API requests are target-aware.
Motion requests return HTTP `423` until the server-side portal lease is active.

## Command endpoint

```text
POST /api/command
```

parameter:

```text
cmd=<DB1:TARGET> ...
```

The HTTP handler validates the DB1 destination before queueing.

The command is validated **again** when the command queue consumes it.

This is intentional defense in depth.

---

# 27. Diagnostics system

The portal diagnostics wrapper exposes common and role-specific health.

## Common modules

```text
ESP32
heap
uptime
Wi-Fi
SoftAP clients
portal HTTP activity
SPIFFS
command queue
DB1 routing
runtime topology
reboot-required state
```

## Leg modules

```text
SPI
MCP2515
CAN TX
CAN RX
AS5600 channels
joint state
impedance
actuator output
raw RMD motor angle
AS5600-aligned continuous control angle
boot zero offset and AS5600 cross-check error
portal safety stage, lease, rejects, and torque-pulse state
stop state
HyperSpawn protocol
```

## Center modules

```text
I²C
TCA9548A
IMU channels 0..4
read/probe state
raw accel/gyro
```

## Neck modules

```text
FastAccelStepper runtime
six STEP/DIR channels
motion armed state
software homed state
homing state
target/current step state
software limits
Bluetooth
command counts
open-loop feedback warning
```

## DB1 routing diagnostics

The firmware tracks fields such as:

```text
accepted commands
rejected commands
target mismatches
unsupported targets
broadcast STOP count
last routed target
last routed source
last routed payload
last routed command age
```

---

# 28. SPIFFS configuration

Primary configuration:

```text
/config.txt
```

Current version:

```text
ConfigVersion:6
```

Command protocol marker:

```text
CommandProtocol:DB1
```

Default routing policy:

```text
LegacyUnaddressedCommands:0
```
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

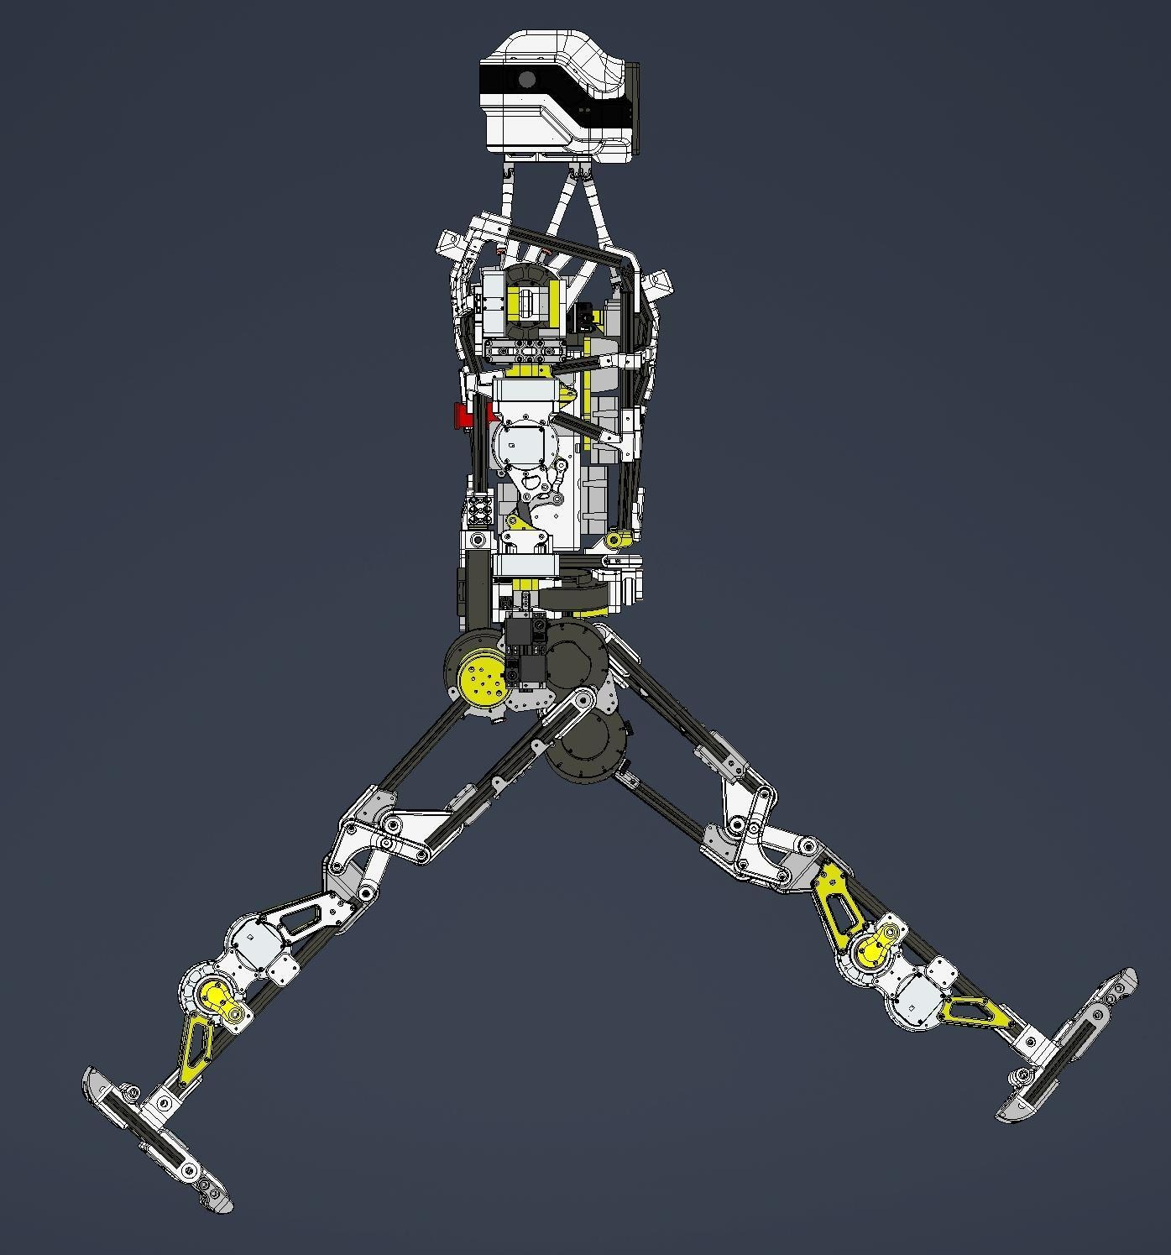
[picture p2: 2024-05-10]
Media/3D Design/Leg-Range-RightView.jpeg

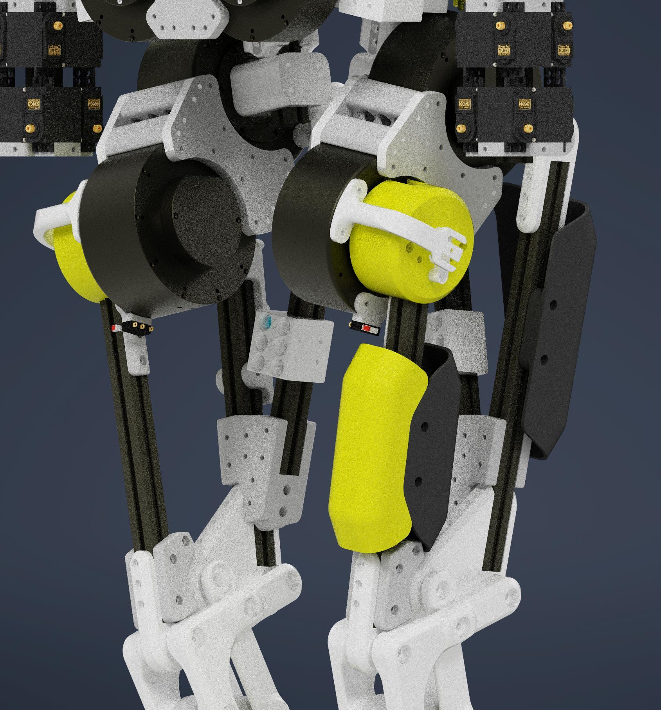
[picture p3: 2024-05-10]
Media/3D Design/Covers-09.jpeg

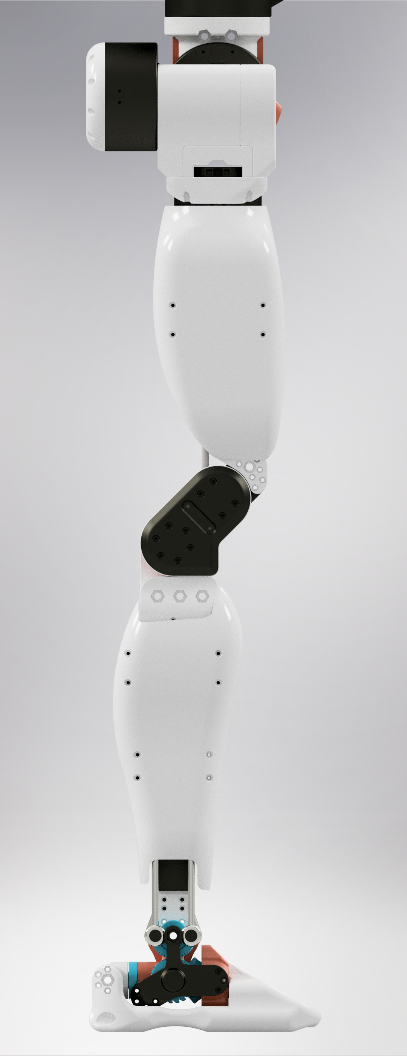
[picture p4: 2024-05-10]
Media/3D Design/sn2787en2ce91.png

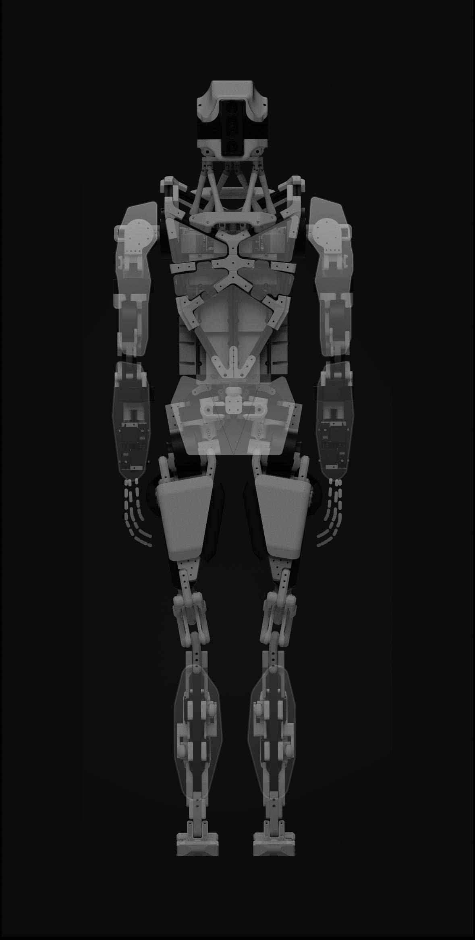
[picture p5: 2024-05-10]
Media/3D Design/RealisedCovers.jpeg

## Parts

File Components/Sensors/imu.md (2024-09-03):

[MPU-9250 IMU Technical Specifications](https://invensense.tdk.com/wp-content/uploads/2015/02/PS-MPU-9250A-01-v1.1.pdf)

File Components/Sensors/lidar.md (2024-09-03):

# LiDAR Sensor

[Technical specs for the Intel Realsense D455](https://www.intelrealsense.com/download/21345/?tmstv=1697035582)

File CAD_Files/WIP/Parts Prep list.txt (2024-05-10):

One single solid part:
Calf-Actuator-Cap.step x4
Knee-L-Bracket.step x4
KneeStrap.step x4

Subassembly:
Foot x2
2020_150mm2;2.step-1

RFoot-ExtrudedAluminium150mm2020Right
RFoot-ExtrudedAluminium150mm2020Left
RFoot-TopCap
RFoot-Toes-Rside
RFoot-Toes-Lside
RFoot-Toe-rotor
RFoot-Tie-rod-ankle-bracket_left
RFoot-Heel-cap
RFoot-Ankle-motor-driver-bracket-right
RFoot-Ankle-motor-driver-bracketleft
RFoot-Heel-rotor
RFoot-Tie-rod-ankle-bracket_right
RFoot-Heel-rotor-center
RFoot-Heel-motor-driver-bracket-right
RFoot-Heel-motor-driver-bracket-left

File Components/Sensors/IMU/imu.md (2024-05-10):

# IMU Sensor

Specifications and usage guide for IMU sensors.

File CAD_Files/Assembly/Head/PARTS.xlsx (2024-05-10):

PARTS | LINKS | POSITION | NOTES | SPECIFICS
M3 Bolts | https://www.amazon.com/Metric-Screws-Suitable-Printer-Assortment/dp/B0B51BFSWZ?s=industrial
M2.5 Bolts | https://www.amazon.com/VIGRUE-Button-Washers-Assortment-Storage/dp/B08VHVB4H5?s=industrial
40mm M2.5 Bolts | https://www.amazon.com/uxcell-Stainless-Steel-Phillips-Screws/dp/B012TE1W4C | GPIO_Rail_AGX.stl
Long Bolts M4 | https://www.amazon.com/iExcell-Grade-Socket-Screws-Finish/dp/B07RTGYB6V | All External
Short Bolts M4 | https://www.amazon.com/iExcell-Grade-Socket-Screws-Finish/dp/B0BN523L2T | All External
M4 Nuts | https://www.amazon.com/Uxcell-a16033100ux0565-Carbon-Steel-Hexagon/dp/B01HGIY1N0 | All External And Internal
AGX ORIN | https://www.amazon.com/NVIDIA-Jetson-Orin-64GB-Developer/dp/B0BYGB3WV4
4G Router | https://www.amazon.com/Wiflyer-WE826-Q-Wireless-Hotspot-T-Mobile/dp/B08BJ5DFTG
Realsense | https://store.intelrealsense.com/buy-intel-realsense-depth-camera-d455f.html
SMA Antennas | https://www.amazon.com/2-4GHz-Wireless-Module-Antenna-Omnidirectional/dp/B076SGTMFS |  | NOTE PIN RP | 2 With Cable, 4 Without (match ports on router)
FAN | https://www.amazon.com/gp/product/B0792BW2VH/ref=ppx_yo_dt_b_search_asin_title?ie=UTF8&psc=1 | mouth.stl | connect to 5V header on AGX

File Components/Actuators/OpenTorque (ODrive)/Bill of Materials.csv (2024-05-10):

Part Name | Count | Source | Alternate Source
AMS AS5048A-TS_EK_AB encoder PCB | 1 | https://www.digikey.com/product-detail/en/ams/AS5048A-TS_EK_AB/AS5048A-AB-1.0-ND/3188612
Herlea X8318S KV100 (Multistar 9235) brushless motor | 1 | https://www.alibaba.com/product-detail/X8318S-Electric-Brushless-Motor-For-RC_60743175936.html | https://hobbyking.com/en_us/9235-100kv-turnigy-multistar-brushless-multi-rotor-motor.html
THK RA8008 cross roller bearing | 1 | https://www.alibaba.com/product-detail/RA8008-crossed-roller-bearing-THK-bearing_1912942608.html
Pemnet IUB-M3-1 threaded insert | 3 | https://estore.dbroberts.com/partdetail.asp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
Pemnet IUB-M3-2 threaded insert | 27 | https://estore.dbroberts.com/partdetail.asp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
M5x30 (h7) steel dowel pin | 3 | Misumi: part number MSH5-30
625ZZ bearing | 3
M2.5x4 hex cap screw | 4
M3x12 hex flat head screw | 23
M3x30 hex flat head screw | 3
M4x16 hex flat head screw | 4

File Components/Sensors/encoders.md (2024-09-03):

[Technical Specifications for the AS5600](https://look.ams-osram.com/m/7059eac7531a86fd/original/AS5600-DS000365.pdf)

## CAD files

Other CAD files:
CAD_Files/Assembly/Full_Body/Solidworks/shadow.SLDASM
CAD_Files/Assembly/Head/head-full-stewart-dynamics.STEP
CAD_Files/WIP/AlignmentFix/New/sldasm/Assem1.SLDASM
CAD_Files/WIP/DropbearwithTieRods/SW/Dropbear_Without_caps.SLDASM
Sim/Gazebo/dropbear_simplified_urdf/meshes/torso/HumanoidBatteryAssembly_Copy_v2_1.stl
Sim/Gazebo/dropbear_detailed_urdf/src/dropbear_detailed_urdf/meshes/head/245-82972-0000-000_asm_07192018_B_1.stl
Sim/Gazebo/dropbear_detailed_urdf/install/dropbear_detailed_urdf/share/dropbear_detailed_urdf/meshes/head/245-82972-0000-000_asm_07192018_B_1.stl
CAD_Files/Assembly/Arm & Hand/Arm/DropbearRightArm.step
CAD_Files/Assembly/Arm & Hand/Hand/Dropbear-HandMechanism (Test).step
CAD_Files/Assembly/Full_Body/dropbear.stp
CAD_Files/Assembly/Head/EXTERNAL_ASSEMBLY/rear-antenna-mount.stl
CAD_Files/Assembly/Head/INTERNAL_ASSEMBLY/realsense-standoff.stl
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

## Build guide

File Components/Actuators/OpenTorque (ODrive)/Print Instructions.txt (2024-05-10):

Nozzle size:
	- 0.6mm
Layer height:
	- 0.2mm or under for Sun Gear, Planet Gears, and Actuator Housing
	- 0.4mm or under for all other parts
Infill:
	- 100% for Sun Gear and Planet Gears
	- 50% cubic infill for all other parts
Perimeters:
	- 4
Material:
	- Nylon for Sun Gear, Planet Gears and Actuator Housing (recommended: Polymaker CoPA)
	- Nylon, ABS, or Polycarbonate for all other parts

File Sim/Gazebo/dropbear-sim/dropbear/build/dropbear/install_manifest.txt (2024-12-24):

/home/gateway/dropbear-humanoid-robot/dropbear/install/dropbear/lib/dropbear/hand_trajectory_publisher.py
/home/gateway/dropbear-humanoid-robot/dropbear/install/dropbear/lib/dropbear/leg_trajectory_publisher.py
/home/gateway/dropbear-humanoid-robot/dropbear/install/dropbear/lib/dropbear/pelvic_girdle_joints_trajectory_publisher.py
/home/gateway/dropbear-humanoid-robot/dropbear/install/dropbear/share/dropbear/launch/dropbear_sdf.launch.py
/home/gateway/dropbear-humanoid-robot/dropbear/install/dropbear/share/dropbear/launch/dropbear_controllers.launch.py
/home/gateway/dropbear-humanoid-robot/dropbear/install/dropbear/share/dropbear/launch/dropbear_detailed_gazebo.launch.py
/home/gateway/dropbear-humanoid-robot/dropbear/install/dropbear/share/dropbear/launch/dropbear_detailed_display.launch.py
/home/gateway/dropbear-humanoid-robot/dropbear/install/dropbear/share/dropbear/meshes/battery/naval-strap_1.stl
/home/gateway/dropbear-humanoid-robot/dropbear/install/dropbear/share/dropbear/meshes/battery/Power_Converter_1.stl
/home/gateway/dropbear-humanoid-robot/dropbear/install/dropbear/share/dropbear/meshes/battery/battery-board-adapter_1.stl
/home/gateway/dropbear-humanoid-robot/dropbear/install/dropbear/share/dropbear/meshes/battery/naval_1.stl
/home/gateway/dropbear-humanoid-robot/dropbear/install/dropbear/share/dropbear/meshes/battery/5v-module__1__1.stl
/home/gateway/dropbear-humanoid-robot/dropbear/install/dropbear/share/dropbear/meshes/battery/battery__1___1__1.stl
/home/gateway/dropbear-humanoid-robot/dropbear/install/dropbear/share/dropbear/meshes/battery/battery-frame-top_1.stl
/home/gateway/dropbear-humanoid-robot/dropbear/install/dropbear/share/dropbear/meshes/battery/mpu1__1__1.stl
/home/gateway/dropbear-humanoid-robot/dropbear/install/dropbear/share/dropbear/meshes/battery/power-module-large__8__1.stl
/home/gateway/dropbear-humanoid-robot/dropbear/install/dropbear/share/dropbear/meshes/battery/power-module-large__9__1.stl
/home/gateway/dropbear-humanoid-robot/dropbear/install/dropbear/share/dropbear/meshes/battery/power-module-large__2__1.stl
/home/gateway/dropbear-humanoid-robot/dropbear/install/dropbear/share/dropbear/meshes/battery/base_link.stl
/home/gateway/dropbear-humanoid-robot/dropbear/install/dropbear/share/dropbear/meshes/battery/battery-frame-bottom_1.stl
/home/gateway/dropbear-humanoid-robot/dropbear/install/dropbear/share/dropbear/meshes/battery/power-module-large__5__1.stl
/home/gateway/dropbear-humanoid-robot/dropbear/install/dropbear/share/dropbear/meshes/battery/esp1_1.stl
/home/gateway/dropbear-humanoid-robot/dropbear/install/dropbear/share/dropbear/meshes/battery/power-module-large_1.stl
/home/gateway/dropbear-humanoid-robot/dropbear/install/dropbear/share/dropbear/meshes/battery/Power_Converter__2__1.stl
/home/gateway/dropbear-humanoid-robot/dropbear/install/dropbear/share/dropbear/meshes/battery/24ah-adapter_1.stl
/home/gateway/dropbear-humanoid-robot/dropbear/install/dropbear/share/dropbear/meshes/battery/power-module-large__1__1.stl
/home/gateway/dropbear-humanoid-robot/dropbear/install/dropbear/share/dropbear/meshes/battery/power-module-large__7__1.stl
/home/gateway/dropbear-humanoid-robot/dropbear/install/dropbear/share/dropbear/meshes/battery/power-module-large__4__1.stl
/home/gateway/dropbear-humanoid-robot/dropbear/install/dropbear/share/dropbear/meshes/battery/mcp1_1.stl
/home/gateway/dropbear-humanoid-robot/dropbear/install/dropbear/share/dropbear/meshes/battery/5v-module_1.stl
/home/gateway/dropbear-humanoid-robot/dropbear/install/dropbear/share/dropbear/meshes/battery/power-module-large__6__1.stl
/home/gateway/dropbear-humanoid-robot/dropbear/install/dropbear/share/dropbear/meshes/battery/power-module-large__3__1.stl
/home/gateway/dropbear-humanoid-robot/dropbear/install/dropbear/share/dropbear/meshes/rightarm/forearm-elbow-motor-bracket-inner_1.stl
/home/gateway/dropbear-humanoid-robot/dropbear/install/dropbear/share/dropbear/meshes/rightarm/top-bracket-servo-strap_1.stl
/home/gateway/dropbear-humanoid-robot/dropbear/install/dropbear/share/dropbear/meshes/rightarm/MG995__4__1.stl
/home/gateway/dropbear-humanoid-robot/dropbear/install/dropbear/share/dropbear/meshes/rightarm/RMD-X8-Pro_MIR8_MIR1__4__1.stl
/home/gateway/dropbear-humanoid-robot/dropbear/install/dropbear/share/dropbear/meshes/rightarm/MG995__6__1.stl
/home/gateway/dropbear-humanoid-robot/dropbear/install/dropbear/share/dropbear/meshes/rightarm/fore-arm-bicep-motor-attatch_1.stl
/home/gateway/dropbear-humanoid-robot/dropbear/install/dropbear/share/dropbear/meshes/rightarm/arm-cuff-bicep-bracket_1.stl
/home/gateway/dropbear-humanoid-robot/dropbear/install/dropbear/share/dropbear/meshes/rightarm/bicep-rear-motor-adapter_1.stl
/home/gateway/dropbear-humanoid-robot/dropbear/install/dropbear/share/dropbear/meshes/rightarm/shoulder-ex-al-interface__2__1.stl
/home/gateway/dropbear-humanoid-robot/dropbear/install/dropbear/share/dropbear/meshes/rightarm/6mm-bearing__2__1.stl
/home/gateway/dropbear-humanoid-robot/dropbear/install/dropbear/share/dropbear/meshes/rightarm/6mm-bearing__4__1.stl
/home/gateway/dropbear-humanoid-robot/dropbear/install/dropbear/share/dropbear/meshes/rightarm/skateboard-bearing__7__1.stl
/home/gateway/dropbear-humanoid-robot/dropbear/install/dropbear/share/dropbear/meshes/rightarm/6mm-bearing__6__1.stl
/home/gateway/dropbear-humanoid-robot/dropbear/install/dropbear/share/dropbear/meshes/rightarm/MG995__2__1.stl
/home/gateway/dropbear-humanoid-robot/dropbear/install/dropbear/share/dropbear/meshes/rightarm/6mm-bearing__3__1.stl
/home/gateway/dropbear-humanoid-robot/dropbear/install/dropbear/share/dropbear/meshes/rightarm/yaw-waist-adapter-motor-exal_MIR1_1.stl
/home/gateway/dropbear-humanoid-robot/dropbear/install/dropbear/share/dropbear/meshes/rightarm/RMD-X8-Pro_MIR8_MIR1__2__1.stl
/home/gateway/dropbear-humanoid-robot/dropbear/install/dropbear/share/dropbear/meshes/rightarm/2020_100mm__10__1.stl
/home/gateway/dropbear-humanoid-robot/dropbear/install/dropbear/share/dropbear/meshes/rightarm/shoulder-cap_1.stl
/home/gateway/dropbear-humanoid-robot/dropbear/install/dropbear/share/dropbear/meshes/rightarm/shoulder-roll-al-mot_MIR1__3__1.stl
/home/gateway/dropbear-humanoid-robot/dropbear/install/dropbear/share/dropbear/meshes/rightarm/top-bracket-servo-strap__1__1.stl
/home/gateway/dropbear-humanoid-robot/dropbear/install/dropbear/share/dropbear/meshes/rightarm/elbow_v2_1.stl
/home/gateway/dropbear-humanoid-robot/dropbear/install/dropbear/share/dropbear/meshes/rightarm/shoulder-ex-al-interface_1.stl
/home/gateway/dropbear-humanoid-robot/dropbear/install/dropbear/share/dropbear/meshes/rightarm/base_link.stl
/home/gateway/dropbear-humanoid-robot/dropbear/install/dropbear/share/dropbear/meshes/rightarm/shoulder-roll-al-mot_MIR1__1__1.stl
/home/gateway/dropbear-humanoid-robot/dropbear/install/dropbear/share/dropbear/meshes/rightarm/RMD-X8-Pro_MIR8_MIR1__3__1.stl
/home/gateway/dropbear-humanoid-robot/dropbear/install/dropbear/share/dropbear/meshes/rightarm/second-forearm-motor-strap_1.stl
/home/gateway/dropbear-humanoid-robot/dropbear/install/dropbear/share/dropbear/meshes/rightarm/yaw-cap_1.stl
/home/gateway/dropbear-humanoid-robot/dropbear/install/dropbear/share/dropbear/meshes/rightarm/bicep-motor-mate_1.stl
/home/gateway/dropbear-humanoid-robot/dropbear/install/dropbear/share/dropbear/meshes/rightarm/6mm-bearing_1.stl
/home/gateway/dropbear-humanoid-robot/dropbear/install/dropbear/share/dropbear/meshes/rightarm/bicep-rotational-cuff-second-motor-bracket_1.stl
/home/gateway/dropbear-humanoid-robot/dropbear/install/dropbear/share/dropbear/meshes/rightarm/MG995__1__1.stl
/home/gateway/dropbear-humanoid-robot/dropbear/install/dropbear/share/dropbear/meshes/rightarm/6mm-bearing__7__1.stl
/home/gateway/dropbear-humanoid-robot/dropbear/install/dropbear/share/dropbear/meshes/rightarm/2020_100mm__11__1.stl
/home/gateway/dropbear-humanoid-robot/dropbear/install/dropbear/share/dropbear/meshes/rightarm/bicep_1.stl
/home/gateway/dropbear-humanoid-robot/dropbear/install/dropbear/share/dropbear/meshes/rightarm/shoulder-ex-al-interface__1__1.stl
/home/gateway/dropbear-humanoid-robot/dropbear/install/dropbear/share/dropbear/meshes/rightarm/yaw-waist-adapter-motor-exal_MIR1__5__1.stl
/home/gateway/dropbear-humanoid-robot/dropbear/install/dropbear/share/dropbear/meshes/rightarm/bicep-shoulder-bracket-exal__3__1.stl
/home/gateway/dropbear-humanoid-robot/dropbear/install/dropbear/share/dropbear/meshes/rightarm/6mm-bearing__5__1.stl
/home/gateway/dropbear-humanoid-robot/dropbear/install/dropbear/share/dropbear/meshes/rightarm/6mm-bearing__1__1.stl
/home/gateway/dropbear-humanoid-robot/dropbear/install/dropbear/share/dropbear/meshes/rightarm/elbow-rear-hanger_1.stl
/home/gateway/dropbear-humanoid-robot/dropbear/install/dropbear/share/dropbear/meshes/rightarm/power-mount-arm_1.stl
/home/gateway/dropbear-humanoid-robot/dropbear/install/dropbear/share/dropbear/meshes/rightarm/MG995_1.stl
/home/gateway/dropbear-humanoid-robot/dropbear/install/dropbear/share/dropbear/meshes/rightarm/forearm-elbow-motor-bracket-inner2_1.stl
/home/gateway/dropbear-humanoid-robot/dropbear/install/dropbear/share/dropbear/meshes/rightarm/shoulder-roll-al-mot_MIR1__2__1.stl
/home/gateway/dropbear-humanoid-robot/dropbear/install/dropbear/share/dropbear/meshes/rightarm/bicep-shoulder-bracket-exal_1.stl
/home/gateway/dropbear-humanoid-robot/dropbear/install/dropbear/share/dropbear/meshes/rightarm/elbow-hangar_1.stl
/home/gateway/dropbear-humanoid-robot/dropbear/install/dropbear/share/dropbear/meshes/rightarm/shoulder-roll-al-mot_MIR1_1.stl
/home/gateway/dropbear-humanoid-robot/dropbear/install/dropbear/share/dropbear/meshes/rightarm/6mm-bearing__9__1.stl
/home/gateway/dropbear-humanoid-robot/dropbear/install/dropbear/share/dropbear/meshes/rightarm/elbow-bridge-rear_1.stl
/home/gateway/dropbear-humanoid-robot/dropbear/install/dropbear/share/dropbear/meshes/rightarm/multiplex-stack-flat_1.stl
/home/gateway/dropbear-humanoid-robot/dropbear/install/dropbear/share/dropbear/meshes/rightarm/MG995__7__1.stl
/home/gateway/dropbear-humanoid-robot/dropbear/install/dropbear/share/dropbear/meshes/rightarm/shoulder-front_1.stl
/home/gateway/dropbear-humanoid-robot/dropbear/install/dropbear/share/dropbear/meshes/rightarm/2020_100mm__9__1.stl
/home/gateway/dropbear-humanoid-robot/dropbear/install/dropbear/share/dropbear/meshes/rightarm/MG995__5__1.stl
/home/gateway/dropbear-humanoid-robot/dropbear/install/dropbear/share/dropbear/meshes/rightarm/shoulder-motor-bicep-rotor-bracket_1.stl
/home/gateway/dropbear-humanoid-robot/dropbear/install/dropbear/share/dropbear/meshes/rightarm/MG995__3__1.stl
/home/gateway/dropbear-humanoid-robot/dropbear/install/dropbear/share/dropbear/meshes/rightarm/2020_100mm__8___1__1.stl
/home/gateway/dropbear-humanoid-robot/dropbear/install/dropbear/share/dropbear/meshes/rightarm/bicep-shoulder-bracket-exal__2__1.stl
/home/gateway/dropbear-humanoid-robot/dropbear/install/dropbear/share/dropbear/meshes/rightarm/elbow-hangar1_1.stl
/home/gateway/dropbear-humanoid-robot/dropbear/install/dropbear/share/dropbear/meshes/rightarm/6mm-bearing__8__1.stl
/home/gateway/dropbear-humanoid-robot/dropbear/install/dropbear/share/dropbear/meshes/rightarm/RMD-X8-Pro_MIR8_MIR1__1__1.stl
/home/gateway/dropbear-humanoid-robot/dropbear/install/dropbear/share/dropbear/meshes/rightarm/straight-tendon_1.stl
/home/gateway/dropbear-humanoid-robot/dropbear/install/dropbear/share/dropbear/meshes/rightarm/elbow-bridge-rear__1__1.stl
/home/gateway/dropbear-humanoid-robot/dropbear/install/dropbear/share/dropbear/meshes/rightarm/shoulder-front-bearing-adapter_1.stl
/home/gateway/dropbear-humanoid-robot/dropbear/install/dropbear/share/dropbear/meshes/rightarm/elbow-rear-hanger__1__1.stl
/home/gateway/dropbear-humanoid-robot/dropbear/install/dropbear/share/dropbear/meshes/rightarm/fan-mount_1.stl
/home/gateway/dropbear-humanoid-robot/dropbear/install/dropbear/share/dropbear/meshes/rightarm/bicep-shoulder-bracket-exal__1__1.stl
/home/gateway/dropbear-humanoid-robot/dropbear/install/dropbear/share/dropbear/meshes/rightarm/front-bearing-adapter-shoulder_1.stl
/home/gateway/dropbear-humanoid-robot/dropbear/install/dropbear/share/dropbear/meshes/leftleg/RMD-X10-S2_MIR4Stator_1.stl
/home/gateway/dropbear-humanoid-robot/dropbear/install/dropbear/share/dropbear/meshes/leftleg/RMD-X8-Pro_MIR8_MIR1_2.stl
/home/gateway/dropbear-humanoid-robot/dropbear/install/dropbear/share/dropbear/meshes/leftleg/skateboard-bearing_left_1.stl
/home/gateway/dropbear-humanoid-robot/dropbear/install/dropbear/share/dropbear/meshes/leftleg/thigh-nub_1.stl
/home/gateway/dropbear-humanoid-robot/dropbear/install/dropbear/share/dropbear/meshes/leftleg/210mm-tie-rod_v1_1.stl
/home/gateway/dropbear-humanoid-robot/dropbear/install/dropbear/share/dropbear/meshes/leftleg/flank-front__1__1.stl
/home/gateway/dropbear-humanoid-robot/dropbear/install/dropbear/share/dropbear/meshes/leftleg/calf-cover_1.stl
/home/gateway/dropbear-humanoid-robot/dropbear/install/dropbear/share/dropbear/meshes/leftleg/magmount__1__1.stl
/home/gateway/dropbear-humanoid-robot/dropbear/install/dropbear/share/dropbear/meshes/leftleg/bearingstrap_1.stl
/home/gateway/dropbear-humanoid-robot/dropbear/install/dropbear/share/dropbear/meshes/leftleg/limit-bracket-knee_1.stl
/home/gateway/dropbear-humanoid-robot/dropbear/install/dropbear/share/dropbear/meshes/leftleg/DumX290mm_1.stl
/home/gateway/dropbear-humanoid-robot/dropbear/install/dropbear/share/dropbear/meshes/leftleg/tie-rod-ankle-brackket_left1_1.stl
/home/gateway/dropbear-humanoid-robot/dropbear/install/dropbear/share/dropbear/meshes/leftleg/DumX210mm_1.stl
/home/gateway/dropbear-humanoid-robot/dropbear/install/dropbear/share/dropbear/meshes/leftleg/2020_400mm_1.stl
/home/gateway/dropbear-humanoid-robot/dropbear/install/dropbear/share/dropbear/meshes/leftleg/conjstraint-knee-test-oute_1.stl
/home/gateway/dropbear-humanoid-robot/dropbear/install/dropbear/share/dropbear/meshes/leftleg/calf-motor-driver-ext_1.stl
/home/gateway/dropbear-humanoid-robot/dropbear/install/dropbear/share/dropbear/meshes/leftleg/leg-thigh-knee-support-bottom_1.stl
/home/gateway/dropbear-humanoid-robot/dropbear/install/dropbear/share/dropbear/meshes/leftleg/new-heel_1.stl
/home/gateway/dropbear-humanoid-robot/dropbear/install/dropbear/share/dropbear/meshes/leftleg/ankle-side-bracket_2.stl
/home/gateway/dropbear-humanoid-robot/dropbear/install/dropbear/share/dropbear/meshes/leftleg/skateboard-bearing__12__1.stl
/home/gateway/dropbear-humanoid-robot/dropbear/install/dropbear/share/dropbear/meshes/leftleg/flank_1.stl
/home/gateway/dropbear-humanoid-robot/dropbear/install/dropbear/share/dropbear/meshes/leftleg/flank__1__1.stl
/home/gateway/dropbear-humanoid-robot/dropbear/install/dropbear/share/dropbear/meshes/leftleg/double-bracket-10deg_MIR_MIR_MIR_1.stl
/home/gateway/dropbear-humanoid-robot/dropbear/install/dropbear/share/dropbear/meshes/leftleg/heel-bracket_left_1.stl
/home/gateway/dropbear-humanoid-robot/dropbear/install/dropbear/share/dropbear/meshes/leftleg/basis_left_1.stl
/home/gateway/dropbear-humanoid-robot/dropbear/install/dropbear/share/dropbear/meshes/leftleg/flank-front_1.stl
/home/gateway/dropbear-humanoid-robot/dropbear/install/dropbear/share/dropbear/meshes/leftleg/2020_150mm__6__2.stl
/home/gateway/dropbear-humanoid-robot/dropbear/install/dropbear/share/dropbear/meshes/leftleg/2020_150mm__1___1__1.stl
/home/gateway/dropbear-humanoid-robot/dropbear/install/dropbear/share/dropbear/meshes/leftleg/heel-bracketleft_1.stl
/home/gateway/dropbear-humanoid-robot/dropbear/install/dropbear/share/dropbear/meshes/leftleg/bearing-sensor-adapter_2.stl
/home/gateway/dropbear-humanoid-robot/dropbear/install/dropbear/share/dropbear/meshes/leftleg/base_link.stl
/home/gateway/dropbear-humanoid-robot/dropbear/install/dropbear/share/dropbear/meshes/leftleg/RMD-X10-S2_MIR4__3_Rotor_1.stl
/home/gateway/dropbear-humanoid-robot/dropbear/install/dropbear/share/dropbear/meshes/leftleg/calf-skin_flip_1.stl
/home/gateway/dropbear-humanoid-robot/dropbear/install/dropbear/share/dropbear/meshes/leftleg/2020_300mm__1__1.stl
/home/gateway/dropbear-humanoid-robot/dropbear/install/dropbear/share/dropbear/meshes/leftleg/skateboard-bearing__15__1.stl
/home/gateway/dropbear-humanoid-robot/dropbear/install/dropbear/share/dropbear/meshes/leftleg/hip-motor-bracket-v5-right_MIR_1.stl
/home/gateway/dropbear-humanoid-robot/dropbear/install/dropbear/share/dropbear/meshes/leftleg/bearingstrap__1__1.stl
/home/gateway/dropbear-humanoid-robot/dropbear/install/dropbear/share/dropbear/meshes/leftleg/skateboard-bearing__9__1.stl
/home/gateway/dropbear-humanoid-robot/dropbear/install/dropbear/share/dropbear/meshes/leftleg/skateboard-bearing__19__1.stl
/home/gateway/dropbear-humanoid-robot/dropbear/install/dropbear/share/dropbear/meshes/leftleg/knee-strap-second-test__1__1.stl
/home/gateway/dropbear-humanoid-robot/dropbear/install/dropbear/share/dropbear/meshes/leftleg/heel-top_MIRleft_1.stl
/home/gateway/dropbear-humanoid-robot/dropbear/install/dropbear/share/dropbear/meshes/leftleg/motor-calf-exal-mount_4.stl
/home/gateway/dropbear-humanoid-robot/dropbear/install/dropbear/share/dropbear/meshes/leftleg/calf-skin_1.stl
/home/gateway/dropbear-humanoid-robot/dropbear/install/dropbear/share/dropbear/meshes/leftleg/knee-strap-second-test_1.stl
/home/gateway/dropbear-humanoid-robot/dropbear/install/dropbear/share/dropbear/meshes/leftleg/RMD-X10-S2_MIR4Rotor_1.stl
/home/gateway/dropbear-humanoid-robot/dropbear/install/dropbear/share/dropbear/meshes/leftleg/ankle-side-bracket_1.stl
/home/gateway/dropbear-humanoid-robot/dropbear/install/dropbear/share/dropbear/meshes/leftleg/leg-pitch-elastic__3__1.stl
/home/gateway/dropbear-humanoid-robot/dropbear/install/dropbear/share/dropbear/meshes/leftleg/bearing-sensor-adapter-arm_1.stl
/home/gateway/dropbear-humanoid-robot/dropbear/install/dropbear/share/dropbear/meshes/leftleg/ankle-thick_1.stl
/home/gateway/dropbear-humanoid-robot/dropbear/install/dropbear/share/dropbear/meshes/leftleg/knee-bend-motor-bracket-hip_1.stl
/home/gateway/dropbear-humanoid-robot/dropbear/install/dropbear/share/dropbear/meshes/leftleg/heel-topleft_1.stl
/home/gateway/dropbear-humanoid-robot/dropbear/install/dropbear/share/dropbear/meshes/leftleg/RMD-X8-Pro_MIR8_MIR1_1.stl
/home/gateway/dropbear-humanoid-robot/dropbear/install/dropbear/share/dropbear/meshes/leftleg/RMD-X10-S2_MIR4__3_Stator_1.stl
/home/gateway/dropbear-humanoid-robot/dropbear/install/dropbear/share/dropbear/meshes/leftleg/skateboard-bearing__14__1.stl
/home/gateway/dropbear-humanoid-robot/dropbear/install/dropbear/share/dropbear/meshes/leftleg/toes-rotor_1.stl
/home/gateway/dropbear-humanoid-robot/dropbear/install/dropbear/share/dropbear/meshes/leftleg/leg-pitch-elastic__1__1.stl
/home/gateway/dropbear-humanoid-robot/dropbear/install/dropbear/share/dropbear/meshes/leftleg/knee-bend-motor-bracket-hip__1__1.stl
/home/gateway/dropbear-humanoid-robot/dropbear/install/dropbear/share/dropbear/meshes/leftleg/heel-connector_1.stl
/home/gateway/dropbear-humanoid-robot/dropbear/install/dropbear/share/dropbear/meshes/leftleg/NO-NC_Bump_Switch_1.stl
/home/gateway/dropbear-humanoid-robot/dropbear/install/dropbear/share/dropbear/meshes/leftleg/thigh-outer-encoder-mount__1__1.stl
/home/gateway/dropbear-humanoid-robot/dropbear/install/dropbear/share/dropbear/meshes/leftleg/skateboard-bearing_1.stl
/home/gateway/dropbear-humanoid-robot/dropbear/install/dropbear/share/dropbear/meshes/leftleg/motor-calf-exal-mount_2.stl
/home/gateway/dropbear-humanoid-robot/dropbear/install/dropbear/share/dropbear/meshes/leftleg/leg-pitch-elastic_1.stl
/home/gateway/dropbear-humanoid-robot/dropbear/install/dropbear/share/dropbear/meshes/leftleg/motorcap-KNEE_MIR_1.stl
/home/gateway/dropbear-humanoid-robot/dropbear/install/dropbear/share/dropbear/meshes/leftleg/foot-imu-strap_1.stl
/home/gateway/dropbear-humanoid-robot/dropbear/install/dropbear/share/dropbear/meshes/leftleg/6band__5__1.stl
/home/gateway/dropbear-humanoid-robot/dropbear/install/dropbear/share/dropbear/meshes/leftleg/dumXrigid_1.stl
/home/gateway/dropbear-humanoid-robot/dropbear/install/dropbear/share/dropbear/meshes/leftleg/calf-lower-bracket_1.stl
/home/gateway/dropbear-humanoid-robot/dropbear/install/dropbear/share/dropbear/meshes/leftleg/2020_100mm__12__1.stl
/home/gateway/dropbear-humanoid-robot/dropbear/install/dropbear/share/dropbear/meshes/leftleg/skateboard-bearing__10__1.stl
/home/gateway/dropbear-humanoid-robot/dropbear/install/dropbear/share/dropbear/meshes/leftleg/2020_300mm__2__1.stl
/home/gateway/dropbear-humanoid-robot/dropbear/install/dropbear/share/dropbear/meshes/leftleg/hip-motor-bracket-v5-right_MIR__1__1.stl
/home/gateway/dropbear-humanoid-robot/dropbear/install/dropbear/share/dropbear/meshes/leftleg/bearing-sensor-adapter_1.stl
/home/gateway/dropbear-humanoid-robot/dropbear/install/dropbear/share/dropbear/meshes/leftleg/new-heel-opposing_1.stl
/home/gateway/dropbear-humanoid-robot/dropbear/install/dropbear/share/dropbear/meshes/leftleg/2020_150mm__6__1.stl
/home/gateway/dropbear-humanoid-robot/dropbear/install/dropbear/share/dropbear/meshes/leftleg/calf-motor-driver-ext_2.stl
/home/gateway/dropbear-humanoid-robot/dropbear/install/dropbear/share/dropbear/meshes/leftleg/mpu1_1.stl
/home/gateway/dropbear-humanoid-robot/dropbear/install/dropbear/share/dropbear/meshes/leftleg/skateboard-bearing__11__1.stl
/home/gateway/dropbear-humanoid-robot/dropbear/install/dropbear/share/dropbear/meshes/leftleg/toes_1.stl
/home/gateway/dropbear-humanoid-robot/dropbear/install/dropbear/share/dropbear/meshes/leftleg/thigh-bracket_1.stl
/home/gateway/dropbear-humanoid-robot/dropbear/install/dropbear/share/dropbear/meshes/leftleg/double-bracket_1.stl
/home/gateway/dropbear-humanoid-robot/dropbear/install/dropbear/share/dropbear/meshes/leftleg/bearingstrap-inner-thigh_1.stl
/home/gateway/dropbear-humanoid-robot/dropbear/install/dropbear/share/dropbear/meshes/leftleg/NO-NC_Bump_Switch__1__1.stl
/home/gateway/dropbear-humanoid-robot/dropbear/install/dropbear/share/dropbear/meshes/leftleg/290mm-tie-rod_v1_1.stl
/home/gateway/dropbear-humanoid-robot/dropbear/install/dropbear/share/dropbear/meshes/leftleg/skateboard-bearing__8__1.stl
/home/gateway/dropbear-humanoid-robot/dropbear/install/dropbear/share/dropbear/meshes/leftleg/ankle-motor-driver-bracket_left_1.stl
/home/gateway/dropbear-humanoid-robot/dropbear/install/dropbear/share/dropbear/meshes/leftleg/heel-roller_1.stl
/home/gateway/dropbear-humanoid-robot/dropbear/install/dropbear/share/dropbear/meshes/leftleg/skateboard-bearing_left_2.stl
/home/gateway/dropbear-humanoid-robot/dropbear/install/dropbear/share/dropbear/meshes/leftleg/calf-lower-bracket_left_1.stl
/home/gateway/dropbear-humanoid-robot/dropbear/install/dropbear/share/dropbear/meshes/leftleg/skateboard-bearing__16__1.stl
/home/gateway/dropbear-humanoid-robot/dropbear/install/dropbear/share/dropbear/meshes/leftleg/innner-thigh-magnet-encoder__1__1.stl
/home/gateway/dropbear-humanoid-robot/dropbear/install/dropbear/share/dropbear/meshes/leftleg/skateboard-bearing__18__1.stl
/home/gateway/dropbear-humanoid-robot/dropbear/install/dropbear/share/dropbear/meshes/leftleg/motor-calf-exal-mount_3.stl
/home/gateway/dropbear-humanoid-robot/dropbear/install/dropbear/share/dropbear/meshes/leftleg/skateboard-bearing__17__1.stl
/home/gateway/dropbear-humanoid-robot/dropbear/install/dropbear/share/dropbear/meshes/leftleg/skateboard-bearing__20__1.stl
/home/gateway/dropbear-humanoid-robot/dropbear/install/dropbear/share/dropbear/meshes/leftleg/knee-lock-2-b_1.stl
/home/gateway/dropbear-humanoid-robot/dropbear/install/dropbear/share/dropbear/meshes/leftleg/motor-calf-exal-mount_1.stl
/home/gateway/dropbear-humanoid-robot/dropbear/install/dropbear/share/dropbear/meshes/leftleg/skateboard-bearing__13__1.stl
/home/gateway/dropbear-humanoid-robot/dropbear/install/dropbear/share/dropbear/meshes/leftleg/flank-front-flipped_1.stl
/home/gateway/dropbear-humanoid-robot/dropbear/install/dropbear/share/dropbear/meshes/leftleg/wire-clip_1.stl
/home/gateway/dropbear-humanoid-robot/dropbear/install/dropbear/share/dropbear/meshes/leftleg/calf-cover_2.stl
/home/gateway/dropbear-humanoid-robot/dropbear/install/dropbear/share/dropbear/meshes/leftleg/bearing-sensor-adapter-arm_2.stl
/home/gateway/dropbear-humanoid-robot/dropbear/install/dropbear/share/dropbear/meshes/leftleg/leg-pitch-elastic__2__1.stl
/home/gateway/dropbear-humanoid-robot/dropbear/install/dropbear/share/dropbear/meshes/leftleg/conjstraint-knee-test-oute_MIR_1.stl
/home/gateway/dropbear-humanoid-robot/dropbear/install/dropbear/share/dropbear/meshes/leftleg/400mmexal_MIR2_MIR3_1.stl
/home/gateway/dropbear-humanoid-robot/dropbear/install/dropbear/share/dropbear/meshes/leftleg/ankle-motor-driver-bracketleft_1.stl
/home/gateway/dropbear-humanoid-robot/dropbear/install/dropbear/share/dropbear/meshes/leftleg/foot-top_1.stl
/home/gateway/dropbear-humanoid-robot/dropbear/install/dropbear/share/dropbear/meshes/leftleg/hip-ex-al-base_MIR_1.stl
/home/gateway/dropbear-humanoid-robot/dropbear/install/dropbear/share/dropbear/meshes/leftleg/multiplex-stack_1.stl
/home/gateway/dropbear-humanoid-robot/dropbear/install/dropbear/share/dropbear/meshes/leftleg/tie-rod-ankle-brackket_left_1.stl
/home/gateway/dropbear-humanoid-robot/dropbear/install/dropbear/share/dropbear/meshes/leftarm/forearm-elbow-motor-bracket-inner_1.stl
/home/gateway/dropbear-humanoid-robot/dropbear/install/dropbear/share/dropbear/meshes/leftarm/top-bracket-servo-strap_1.stl
/home/gateway/dropbear-humanoid-robot/dropbear/install/dropbear/share/dropbear/meshes/leftarm/MG995__4__1.stl
/home/gateway/dropbear-humanoid-robot/dropbear/install/dropbear/share/dropbear/meshes/leftarm/RMD-X8-Pro_MIR8_MIR1__4__1.stl
/home/gateway/dropbear-humanoid-robot/dropbear/install/dropbear/share/dropbear/meshes/leftarm/MG995__6__1.stl
/home/gateway/dropbear-humanoid-robot/dropbear/install/dropbear/share/dropbear/meshes/leftarm/fore-arm-bicep-motor-attatch_1.stl
/home/gateway/dropbear-humanoid-robot/dropbear/install/dropbear/share/dropbear/meshes/leftarm/arm-cuff-bicep-bracket_1.stl
/home/gateway/dropbear-humanoid-robot/dropbear/install/dropbear/share/dropbear/meshes/leftarm/bicep-rear-motor-adapter_1.stl
/home/gateway/dropbear-humanoid-robot/dropbear/install/dropbear/share/dropbear/meshes/leftarm/shoulder-ex-al-interface__2__1.stl
/home/gateway/dropbear-humanoid-robot/dropbear/install/dropbear/share/dropbear/meshes/leftarm/6mm-bearing__2__1.stl
/home/gateway/dropbear-humanoid-robot/dropbear/install/dropbear/share/dropbear/meshes/leftarm/6mm-bearing__4__1.stl
/home/gateway/dropbear-humanoid-robot/dropbear/install/dropbear/share/dropbear/meshes/leftarm/skateboard-bearing__7__1.stl
/home/gateway/dropbear-humanoid-robot/dropbear/install/dropbear/share/dropbear/meshes/leftarm/6mm-bearing__6__1.stl
/home/gateway/dropbear-humanoid-robot/dropbear/install/dropbear/share/dropbear/meshes/leftarm/MG995__2__1.stl
/home/gateway/dropbear-humanoid-robot/dropbear/install/dropbear/share/dropbear/meshes/leftarm/6mm-bearing__3__1.stl
/home/gateway/dropbear-humanoid-robot/dropbear/install/dropbear/share/dropbear/meshes/leftarm/yaw-waist-adapter-motor-exal_MIR1_1.stl
/home/gateway/dropbear-humanoid-robot/dropbear/install/dropbear/share/dropbear/meshes/leftarm/RMD-X8-Pro_MIR8_MIR1__2__1.stl
/home/gateway/dropbear-humanoid-robot/dropbear/install/dropbear/share/dropbear/meshes/leftarm/2020_100mm__10__1.stl
/home/gateway/dropbear-humanoid-robot/dropbear/install/dropbear/share/dropbear/meshes/leftarm/shoulder-cap_1.stl
/home/gateway/dropbear-humanoid-robot/dropbear/install/dropbear/share/dropbear/meshes/leftarm/shoulder-roll-al-mot_MIR1__3__1.stl
/home/gateway/dropbear-humanoid-robot/dropbear/install/dropbear/share/dropbear/meshes/leftarm/top-bracket-servo-strap__1__1.stl
/home/gateway/dropbear-humanoid-robot/dropbear/install/dropbear/share/dropbear/meshes/leftarm/shoulder-ex-al-interface_1.stl
/home/gateway/dropbear-humanoid-robot/dropbear/install/dropbear/share/dropbear/meshes/leftarm/base_link.stl
/home/gateway/dropbear-humanoid-robot/dropbear/install/dropbear/share/dropbear/meshes/leftarm/shoulder-roll-al-mot_MIR1__1__1.stl
/home/gateway/dropbear-humanoid-robot/dropbear/install/dropbear/share/dropbear/meshes/leftarm/RMD-X8-Pro_MIR8_MIR1__3__1.stl
/home/gateway/dropbear-humanoid-robot/dropbear/install/dropbear/share/dropbear/meshes/leftarm/second-forearm-motor-strap_1.stl
/home/gateway/dropbear-humanoid-robot/dropbear/install/dropbear/share/dropbear/meshes/leftarm/yaw-cap_1.stl
/home/gateway/dropbear-humanoid-robot/dropbear/install/dropbear/share/dropbear/meshes/leftarm/bicep-motor-mate_1.stl
/home/gateway/dropbear-humanoid-robot/dropbear/install/dropbear/share/dropbear/meshes/leftarm/6mm-bearing_1.stl
/home/gateway/dropbear-humanoid-robot/dropbear/install/dropbear/share/dropbear/meshes/leftarm/bicep-rotational-cuff-second-motor-bracket_1.stl
/home/gateway/dropbear-humanoid-robot/dropbear/install/dropbear/share/dropbear/meshes/leftarm/MG995__1__1.stl
/home/gateway/dropbear-humanoid-robot/dropbear/install/dropbear/share/dropbear/meshes/leftarm/6mm-bearing__7__1.stl
/home/gateway/dropbear-humanoid-robot/dropbear/install/dropbear/share/dropbear/meshes/leftarm/2020_100mm__11__1.stl
/home/gateway/dropbear-humanoid-robot/dropbear/install/dropbear/share/dropbear/meshes/leftarm/bicep_1.stl
/home/gateway/dropbear-humanoid-robot/dropbear/install/dropbear/share/dropbear/meshes/leftarm/shoulder-ex-al-interface__1__1.stl
/home/gateway/dropbear-humanoid-robot/dropbear/install/dropbear/share/dropbear/meshes/leftarm/yaw-waist-adapter-motor-exal_MIR1__5__1.stl
/home/gateway/dropbear-humanoid-robot/dropbear/install/dropbear/share/dropbear/meshes/leftarm/bicep-shoulder-bracket-exal__3__1.stl
/home/gateway/dropbear-humanoid-robot/dropbear/install/dropbear/share/dropbear/meshes/leftarm/6mm-bearing__5__1.stl
/home/gateway/dropbear-humanoid-robot/dropbear/install/dropbear/share/dropbear/meshes/leftarm/6mm-bearing__1__1.stl
/home/gateway/dropbear-humanoid-robot/dropbear/install/dropbear/share/dropbear/meshes/leftarm/elbow-rear-hanger_1.stl
/home/gateway/dropbear-humanoid-robot/dropbear/install/dropbear/share/dropbear/meshes/leftarm/power-mount-arm_1.stl
/home/gateway/dropbear-humanoid-robot/dropbear/install/dropbear/share/dropbear/meshes/leftarm/MG995_1.stl
/home/gateway/dropbear-humanoid-robot/dropbear/install/dropbear/share/dropbear/meshes/leftarm/forearm-elbow-motor-bracket-inner2_1.stl
/home/gateway/dropbear-humanoid-robot/dropbear/install/dropbear/share/dropbear/meshes/leftarm/shoulder-roll-al-mot_MIR1__2__1.stl
/home/gateway/dropbear-humanoid-robot/dropbear/install/dropbear/share/dropbear/meshes/leftarm/bicep-shoulder-bracket-exal_1.stl
/home/gateway/dropbear-humanoid-robot/dropbear/install/dropbear/share/dropbear/meshes/leftarm/elbow-hangar_1.stl
/home/gateway/dropbear-humanoid-robot/dropbear/install/dropbear/share/dropbear/meshes/leftarm/shoulder-roll-al-mot_MIR1_1.stl
/home/gateway/dropbear-humanoid-robot/dropbear/install/dropbear/share/dropbear/meshes/leftarm/6mm-bearing__9__1.stl
/home/gateway/dropbear-humanoid-robot/dropbear/install/dropbear/share/dropbear/meshes/leftarm/elbow-bridge-rear_1.stl
/home/gateway/dropbear-humanoid-robot/dropbear/install/dropbear/share/dropbear/meshes/leftarm/multiplex-stack-flat_1.stl
/home/gateway/dropbear-humanoid-robot/dropbear/install/dropbear/share/dropbear/meshes/leftarm/MG995__7__1.stl
/home/gateway/dropbear-humanoid-robot/dropbear/install/dropbear/share/dropbear/meshes/leftarm/shoulder-front_1.stl
/home/gateway/dropbear-humanoid-robot/dropbear/install/dropbear/share/dropbear/meshes/leftarm/2020_100mm__9__1.stl
/home/gateway/dropbear-humanoid-robot/dropbear/install/dropbear/share/dropbear/meshes/leftarm/MG995__5__1.stl
/home/gateway/dropbear-humanoid-robot/dropbear/install/dropbear/share/dropbear/meshes/leftarm/shoulder-motor-bicep-rotor-bracket_1.stl
/home/gateway/dropbear-humanoid-robot/dropbear/install/dropbear/share/dropbear/meshes/leftarm/MG995__3__1.stl
/home/gateway/dropbear-humanoid-robot/dropbear/install/dropbear/share/dropbear/meshes/leftarm/2020_100mm__8___1__1.stl
/home/gateway/dropbear-humanoid-robot/dropbear/install/dropbear/share/dropbear/meshes/leftarm/bicep-shoulder-bracket-exal__2__1.stl
/home/gateway/dropbear-humanoid-robot/dropbear/install/dropbear/share/dropbear/meshes/leftarm/elbow-hangar1_1.stl
/home/gateway/dropbear-humanoid-robot/dropbear/install/dropbear/share/dropbear/meshes/leftarm/6mm-bearing__8__1.stl
/home/gateway/dropbear-humanoid-robot/dropbear/install/dropbear/share/dropbear/meshes/leftarm/RMD-X8-Pro_MIR8_MIR1__1__1.stl
/home/gateway/dropbear-humanoid-robot/dropbear/install/dropbear/share/dropbear/meshes/leftarm/straight-tendon_1.stl
/home/gateway/dropbear-humanoid-robot/dropbear/install/dropbear/share/dropbear/meshes/leftarm/elbow-bridge-rear__1__1.stl
/home/gateway/dropbear-humanoid-robot/dropbear/install/dropbear/share/dropbear/meshes/leftarm/shoulder-front-bearing-adapter_1.stl
/home/gateway/dropbear-humanoid-robot/dropbear/install/dropbear/share/dropbear/meshes/leftarm/elbow-rear-hanger__1__1.stl
/home/gateway/dropbear-humanoid-robot/dropbear/install/dropbear/share/dropbear/meshes/leftarm/fan-mount_1.stl
/home/gateway/dropbear-humanoid-robot/dropbear/install/dropbear/share/dropbear/meshes/leftarm/bicep-shoulder-bracket-exal__1__1.stl
/home/gateway/dropbear-humanoid-robot/dropbear/install/dropbear/share/dropbear/meshes/leftarm/front-bearing-adapter-shoulder_1.stl
/home/gateway/dropbear-humanoid-robot/dropbear/install/dropbear/share/dropbear/meshes/pelvicgirdle/center-waist-aluminum-strap_1.stl
/home/gateway/dropbear-humanoid-robot/dropbear/install/dropbear/share/dropbear/meshes/pelvicgirdle/naval__1__1.stl
/home/gateway/dropbear-humanoid-robot/dropbear/install/dropbear/share/dropbear/meshes/pelvicgirdle/groin-square__1__1.stl
/home/gateway/dropbear-humanoid-robot/dropbear/install/dropbear/share/dropbear/meshes/pelvicgirdle/yaw-waist-adapter-motor-exal_MIR1__4__1.stl
/home/gateway/dropbear-humanoid-robot/dropbear/install/dropbear/share/dropbear/meshes/pelvicgirdle/RMD-X10-S2_MIR4__2_Rotor_1.stl
/home/gateway/dropbear-humanoid-robot/dropbear/install/dropbear/share/dropbear/meshes/pelvicgirdle/skateboard-bearing__4__1.stl
/home/gateway/dropbear-humanoid-robot/dropbear/install/dropbear/share/dropbear/meshes/pelvicgirdle/100m__1__1.stl
/home/gateway/dropbear-humanoid-robot/dropbear/install/dropbear/share/dropbear/meshes/pelvicgirdle/front-motor-roll-nut_1.stl
/home/gateway/dropbear-humanoid-robot/dropbear/install/dropbear/share/dropbear/meshes/pelvicgirdle/skateboard-bearing__2__1.stl
/home/gateway/dropbear-humanoid-robot/dropbear/install/dropbear/share/dropbear/meshes/pelvicgirdle/RMD-X10-V3__1_Stator_1.stl
/home/gateway/dropbear-humanoid-robot/dropbear/install/dropbear/share/dropbear/meshes/pelvicgirdle/butt-mag__1__1.stl
/home/gateway/dropbear-humanoid-robot/dropbear/install/dropbear/share/dropbear/meshes/pelvicgirdle/inner-rear-rocker-bracket_1.stl
/home/gateway/dropbear-humanoid-robot/dropbear/install/dropbear/share/dropbear/meshes/pelvicgirdle/2020_100mm__3___1__1.stl
/home/gateway/dropbear-humanoid-robot/dropbear/install/dropbear/share/dropbear/meshes/pelvicgirdle/100m_1.stl
/home/gateway/dropbear-humanoid-robot/dropbear/install/dropbear/share/dropbear/meshes/pelvicgirdle/center-band-brick__6__1.stl
/home/gateway/dropbear-humanoid-robot/dropbear/install/dropbear/share/dropbear/meshes/pelvicgirdle/yaw-waist-adapter-motor-exal_MIR1__3__1.stl
/home/gateway/dropbear-humanoid-robot/dropbear/install/dropbear/share/dropbear/meshes/pelvicgirdle/hip-roll-al-mot_MIR2_1.stl
/home/gateway/dropbear-humanoid-robot/dropbear/install/dropbear/share/dropbear/meshes/pelvicgirdle/butt-center-rear-bracket_1.stl
/home/gateway/dropbear-humanoid-robot/dropbear/install/dropbear/share/dropbear/meshes/pelvicgirdle/RMD-X10-V3Rotor_1.stl
/home/gateway/dropbear-humanoid-robot/dropbear/install/dropbear/share/dropbear/meshes/pelvicgirdle/side-band-brick-double__1__1.stl
/home/gateway/dropbear-humanoid-robot/dropbear/install/dropbear/share/dropbear/meshes/pelvicgirdle/front-motor-roll-nut__1__1.stl
/home/gateway/dropbear-humanoid-robot/dropbear/install/dropbear/share/dropbear/meshes/pelvicgirdle/100m__3__1.stl
/home/gateway/dropbear-humanoid-robot/dropbear/install/dropbear/share/dropbear/meshes/pelvicgirdle/side-band-brick-double__2__1.stl
/home/gateway/dropbear-humanoid-robot/dropbear/install/dropbear/share/dropbear/meshes/pelvicgirdle/skateboard-bearing__1__1.stl
/home/gateway/dropbear-humanoid-robot/dropbear/install/dropbear/share/dropbear/meshes/pelvicgirdle/base_link.stl
/home/gateway/dropbear-humanoid-robot/dropbear/install/dropbear/share/dropbear/meshes/pelvicgirdle/hip-roll-al-mot_MIR2__3__1.stl
/home/gateway/dropbear-humanoid-robot/dropbear/install/dropbear/share/dropbear/meshes/pelvicgirdle/groin-square_1.stl
/home/gateway/dropbear-humanoid-robot/dropbear/install/dropbear/share/dropbear/meshes/pelvicgirdle/center-band-brick__5__1.stl
/home/gateway/dropbear-humanoid-robot/dropbear/install/dropbear/share/dropbear/meshes/pelvicgirdle/skateboard-bearing__3__1.stl
/home/gateway/dropbear-humanoid-robot/dropbear/install/dropbear/share/dropbear/meshes/pelvicgirdle/hip-roll-al-bracket_MIR__1__1.stl
/home/gateway/dropbear-humanoid-robot/dropbear/install/dropbear/share/dropbear/meshes/pelvicgirdle/side-band-brick-double_1.stl
/home/gateway/dropbear-humanoid-robot/dropbear/install/dropbear/share/dropbear/meshes/pelvicgirdle/hip-roll-al-mot_MIR2__1__1.stl
/home/gateway/dropbear-humanoid-robot/dropbear/install/dropbear/share/dropbear/meshes/pelvicgirdle/RMD-X10-S2_MIR4__1_Stator_1.stl
/home/gateway/dropbear-humanoid-robot/dropbear/install/dropbear/share/dropbear/meshes/pelvicgirdle/hip-roll-front-bracket-strap-motor__2__1.stl
/home/gateway/dropbear-humanoid-robot/dropbear/install/dropbear/share/dropbear/meshes/pelvicgirdle/inner-rear-rocker-bracket_MIR_1.stl
/home/gateway/dropbear-humanoid-robot/dropbear/install/dropbear/share/dropbear/meshes/pelvicgirdle/side-band-brick-double__3__1.stl
/home/gateway/dropbear-humanoid-robot/dropbear/install/dropbear/share/dropbear/meshes/pelvicgirdle/hip-roll-al-mot_MIR2__2__1.stl
/home/gateway/dropbear-humanoid-robot/dropbear/install/dropbear/share/dropbear/meshes/pelvicgirdle/front-bearing-strap__2__1.stl
/home/gateway/dropbear-humanoid-robot/dropbear/install/dropbear/share/dropbear/meshes/pelvicgirdle/butt-adapter-large-motor__1__1.stl
/home/gateway/dropbear-humanoid-robot/dropbear/install/dropbear/share/dropbear/meshes/pelvicgirdle/hip-roll-al-bracket_1.stl
/home/gateway/dropbear-humanoid-robot/dropbear/install/dropbear/share/dropbear/meshes/pelvicgirdle/RMD-X10-S2_MIR4__2_Stator_1.stl
/home/gateway/dropbear-humanoid-robot/dropbear/install/dropbear/share/dropbear/meshes/pelvicgirdle/butt-mag_1.stl
/home/gateway/dropbear-humanoid-robot/dropbear/install/dropbear/share/dropbear/meshes/pelvicgirdle/RMD-X10-V3__1_Rotor_1.stl
/home/gateway/dropbear-humanoid-robot/dropbear/install/dropbear/share/dropbear/meshes/pelvicgirdle/lumbare_1.stl
/home/gateway/dropbear-humanoid-robot/dropbear/install/dropbear/share/dropbear/meshes/pelvicgirdle/motor-yaw-cap_1.stl
/home/gateway/dropbear-humanoid-robot/dropbear/install/dropbear/share/dropbear/meshes/pelvicgirdle/100m__4__1.stl
/home/gateway/dropbear-humanoid-robot/dropbear/install/dropbear/share/dropbear/meshes/pelvicgirdle/bearing-torso-rocker-mount-rear_MIR_1.stl
/home/gateway/dropbear-humanoid-robot/dropbear/install/dropbear/share/dropbear/meshes/pelvicgirdle/front-bearing-strap__1__1.stl
/home/gateway/dropbear-humanoid-robot/dropbear/install/dropbear/share/dropbear/meshes/pelvicgirdle/motor-yaw-cap__3__1.stl
/home/gateway/dropbear-humanoid-robot/dropbear/install/dropbear/share/dropbear/meshes/pelvicgirdle/hip-motor-bracket-v5-right_MIR_MIR2_1.stl
/home/gateway/dropbear-humanoid-robot/dropbear/install/dropbear/share/dropbear/meshes/pelvicgirdle/2020_200mm__1___1__1.stl
/home/gateway/dropbear-humanoid-robot/dropbear/install/dropbear/share/dropbear/meshes/pelvicgirdle/hip-roll-al-bracket__1__1.stl
/home/gateway/dropbear-humanoid-robot/dropbear/install/dropbear/share/dropbear/meshes/pelvicgirdle/2020_100mm__2___1__1.stl
/home/gateway/dropbear-humanoid-robot/dropbear/install/dropbear/share/dropbear/meshes/pelvicgirdle/butt-adapter-large-motor_1.stl
/home/gateway/dropbear-humanoid-robot/dropbear/install/dropbear/share/dropbear/meshes/pelvicgirdle/RMD-X10-V3Stator_1.stl
/home/gateway/dropbear-humanoid-robot/dropbear/install/dropbear/share/dropbear/meshes/pelvicgirdle/yaw-waist-adapter-motor-exal_MIR1__1___1__1.stl
/home/gateway/dropbear-humanoid-robot/dropbear/install/dropbear/share/dropbear/meshes/pelvicgirdle/center-bracket-waist-hips_1.stl
/home/gateway/dropbear-humanoid-robot/dropbear/install/dropbear/share/dropbear/meshes/pelvicgirdle/dumLeftLeg_1.stl
/home/gateway/dropbear-humanoid-robot/dropbear/install/dropbear/share/dropbear/meshes/pelvicgirdle/2020_100mm__5___1__1.stl
/home/gateway/dropbear-humanoid-robot/dropbear/install/dropbear/share/dropbear/meshes/pelvicgirdle/motor-yaw-cap__2__1.stl
/home/gateway/dropbear-humanoid-robot/dropbear/install/dropbear/share/dropbear/meshes/pelvicgirdle/2020_100mm__6___1__1.stl
/home/gateway/dropbear-humanoid-robot/dropbear/install/dropbear/share/dropbear/meshes/pelvicgirdle/hip-roll-front-bracket-strap-motor_1.stl
/home/gateway/dropbear-humanoid-robot/dropbear/install/dropbear/share/dropbear/meshes/pelvicgirdle/bearing-torso-rocker-mount-rear_1.stl
/home/gateway/dropbear-humanoid-robot/dropbear/install/dropbear/share/dropbear/meshes/pelvicgirdle/RMD-X10-S2_MIR4__1_Rotor_1.stl
/home/gateway/dropbear-humanoid-robot/dropbear/install/dropbear/share/dropbear/meshes/pelvicgirdle/bearing-rocker-rear__1__1.stl
/home/gateway/dropbear-humanoid-robot/dropbear/install/dropbear/share/dropbear/meshes/pelvicgirdle/6band__3__1.stl
/home/gateway/dropbear-humanoid-robot/dropbear/install/dropbear/share/dropbear/meshes/pelvicgirdle/front-bearing-strap_1.stl
/home/gateway/dropbear-humanoid-robot/dropbear/install/dropbear/share/dropbear/meshes/pelvicgirdle/encoder-magnet-leg__1__1.stl
/home/gateway/dropbear-humanoid-robot/dropbear/install/dropbear/share/dropbear/meshes/pelvicgirdle/hip-roll-front-bracket-strap-motor__3__1.stl
/home/gateway/dropbear-humanoid-robot/dropbear/install/dropbear/share/dropbear/meshes/pelvicgirdle/skateboard-bearing__6__1.stl
/home/gateway/dropbear-humanoid-robot/dropbear/install/dropbear/share/dropbear/meshes/pelvicgirdle/hip-roll-front-bracket-strap-motor__1__1.stl
/home/gateway/dropbear-humanoid-robot/dropbear/install/dropbear/share/dropbear/meshes/pelvicgirdle/dumRightLeg_1.stl
/home/gateway/dropbear-humanoid-robot/dropbear/install/dropbear/share/dropbear/meshes/pelvicgirdle/motor-yaw-cap__4__1.stl
/home/gateway/dropbear-humanoid-robot/dropbear/install/dropbear/share/dropbear/meshes/pelvicgirdle/hard-limit_1.stl
/home/gateway/dropbear-humanoid-robot/dropbear/install/dropbear/share/dropbear/meshes/pelvicgirdle/hip-roll-al-bracket_MIR_1.stl
/home/gateway/dropbear-humanoid-robot/dropbear/install/dropbear/share/dropbear/meshes/pelvicgirdle/6band__4__1.stl
/home/gateway/dropbear-humanoid-robot/dropbear/install/dropbear/share/dropbear/meshes/pelvicgirdle/100m__2__1.stl
/home/gateway/dropbear-humanoid-robot/dropbear/install/dropbear/share/dropbear/meshes/pelvicgirdle/hip-yaw-chromatic-encoder_1.stl
/home/gateway/dropbear-humanoid-robot/dropbear/install/dropbear/share/dropbear/meshes/pelvicgirdle/encoder-butt__1__1.stl
/home/gateway/dropbear-humanoid-robot/dropbear/install/dropbear/share/dropbear/meshes/pelvicgirdle/2020_100mm__4___1__1.stl
/home/gateway/dropbear-humanoid-robot/dropbear/install/dropbear/share/dropbear/meshes/pelvicgirdle/motor-yaw-cap__1__1.stl
/home/gateway/dropbear-humanoid-robot/dropbear/install/dropbear/share/dropbear/meshes/pelvicgirdle/yaw-waist-adapter-motor-exal_MIR1__2__1.stl
/home/gateway/dropbear-humanoid-robot/dropbear/install/dropbear/share/dropbear/meshes/pelvicgirdle/encoder-magnet-leg_1.stl
/home/gateway/dropbear-humanoid-robot/dropbear/install/dropbear/share/dropbear/meshes/pelvicgirdle/hips-front-mount_1.stl
/home/gateway/dropbear-humanoid-robot/dropbear/install/dropbear/share/dropbear/meshes/pelvicgirdle/encoder-butt_1.stl
/home/gateway/dropbear-humanoid-robot/dropbear/install/dropbear/share/dropbear/meshes/pelvicgirdle/2020_100mm__7___1__1.stl
/home/gateway/dropbear-humanoid-robot/dropbear/install/dropbear/share/dropbear/meshes/pelvicgirdle/motor-yaw-cap__5__1.stl
/home/gateway/dropbear-humanoid-robot/dropbear/install/dropbear/share/dropbear/meshes/pelvicgirdle/2020_100mm__1___1__1.stl
/home/gateway/dropbear-humanoid-robot/dropbear/install/dropbear/share/dropbear/meshes/pelvicgirdle/hard-limit_MIR_1.stl
/home/gateway/dropbear-humanoid-robot/dropbear/install/dropbear/share/dropbear/meshes/pelvicgirdle/skateboard-bearing__5__1.stl
/home/gateway/dropbear-humanoid-robot/dropbear/install/dropbear/share/dropbear/meshes/pelvicgirdle/bearing-rocker-rear_1.stl
/home/gateway/dropbear-humanoid-robot/dropbear/install/dropbear/share/dropbear/meshes/torso/2020_100mm__5__1.stl
/home/gateway/dropbear-humanoid-robot/dropbear/install/dropbear/share/dropbear/meshes/torso/front-right-shoulder_1.stl
/home/gateway/dropbear-humanoid-robot/dropbear/install/dropbear/share/dropbear/meshes/torso/right-rear-shoulder_MIR_1.stl
/home/gateway/dropbear-humanoid-robot/dropbear/install/dropbear/share/dropbear/meshes/torso/head-power-supply-bracket_1.stl
/home/gateway/dropbear-humanoid-robot/dropbear/install/dropbear/share/dropbear/meshes/torso/2020_200mm__8__1.stl
/home/gateway/dropbear-humanoid-robot/dropbear/install/dropbear/share/dropbear/meshes/torso/handle__1__1.stl
/home/gateway/dropbear-humanoid-robot/dropbear/install/dropbear/share/dropbear/meshes/torso/voltage-meter_1.stl
/home/gateway/dropbear-humanoid-robot/dropbear/install/dropbear/share/dropbear/meshes/torso/back-middle-strap_1.stl
/home/gateway/dropbear-humanoid-robot/dropbear/install/dropbear/share/dropbear/meshes/torso/2020_300mm_1.stl
/home/gateway/dropbear-humanoid-robot/dropbear/install/dropbear/share/dropbear/meshes/torso/button-holder_1.stl
/home/gateway/dropbear-humanoid-robot/dropbear/install/dropbear/share/dropbear/meshes/torso/rear-left-spine-support_1.stl
/home/gateway/dropbear-humanoid-robot/dropbear/install/dropbear/share/dropbear/meshes/torso/right-shoulder-motor-adapter_MIR_1.stl
/home/gateway/dropbear-humanoid-robot/dropbear/install/dropbear/share/dropbear/meshes/torso/2020_200mm__3__1.stl
/home/gateway/dropbear-humanoid-robot/dropbear/install/dropbear/share/dropbear/meshes/torso/RMD-X10__1_Stator_1.stl
/home/gateway/dropbear-humanoid-robot/dropbear/install/dropbear/share/dropbear/meshes/torso/2020_200mm__5__1.stl
/home/gateway/dropbear-humanoid-robot/dropbear/install/dropbear/share/dropbear/meshes/torso/2020_100mm__3__1.stl
/home/gateway/dropbear-humanoid-robot/dropbear/install/dropbear/share/dropbear/meshes/torso/2020_350mm_1.stl
/home/gateway/dropbear-humanoid-robot/dropbear/install/dropbear/share/dropbear/meshes/torso/handle_1.stl
/home/gateway/dropbear-humanoid-robot/dropbear/install/dropbear/share/dropbear/meshes/torso/2020_100mm__2__1.stl
/home/gateway/dropbear-humanoid-robot/dropbear/install/dropbear/share/dropbear/meshes/torso/right-front-rib-lower_1.stl
/home/gateway/dropbear-humanoid-robot/dropbear/install/dropbear/share/dropbear/meshes/torso/6band__1__1.stl
/home/gateway/dropbear-humanoid-robot/dropbear/install/dropbear/share/dropbear/meshes/torso/2020_150mm__3__1.stl
/home/gateway/dropbear-humanoid-robot/dropbear/install/dropbear/share/dropbear/meshes/torso/RMD-X10Stator_1.stl
/home/gateway/dropbear-humanoid-robot/dropbear/install/dropbear/share/dropbear/meshes/torso/2020_200mm__7__1.stl
/home/gateway/dropbear-humanoid-robot/dropbear/install/dropbear/share/dropbear/meshes/torso/left-front-rib-lower_1.stl
/home/gateway/dropbear-humanoid-robot/dropbear/install/dropbear/share/dropbear/meshes/torso/right-shoulder-motor-adapter_1.stl
/home/gateway/dropbear-humanoid-robot/dropbear/install/dropbear/share/dropbear/meshes/torso/2020_200mm_1.stl
/home/gateway/dropbear-humanoid-robot/dropbear/install/dropbear/share/dropbear/meshes/torso/base_link.stl
/home/gateway/dropbear-humanoid-robot/dropbear/install/dropbear/share/dropbear/meshes/torso/back-middle-strap__1__1.stl
/home/gateway/dropbear-humanoid-robot/dropbear/install/dropbear/share/dropbear/meshes/torso/neck-chest-interface2_1.stl
/home/gateway/dropbear-humanoid-robot/dropbear/install/dropbear/share/dropbear/meshes/torso/Power_Converter__1__1.stl
/home/gateway/dropbear-humanoid-robot/dropbear/install/dropbear/share/dropbear/meshes/torso/back-bottom-strap-spine__1__1.stl
/home/gateway/dropbear-humanoid-robot/dropbear/install/dropbear/share/dropbear/meshes/torso/2020_100mm__1__1.stl
/home/gateway/dropbear-humanoid-robot/dropbear/install/dropbear/share/dropbear/meshes/torso/dumLeftArm_1.stl
/home/gateway/dropbear-humanoid-robot/dropbear/install/dropbear/share/dropbear/meshes/torso/2020_200mm__2__1.stl
/home/gateway/dropbear-humanoid-robot/dropbear/install/dropbear/share/dropbear/meshes/torso/right-shoulder-top_1.stl
/home/gateway/dropbear-humanoid-robot/dropbear/install/dropbear/share/dropbear/meshes/torso/killswitch-spine-interface_1.stl
/home/gateway/dropbear-humanoid-robot/dropbear/install/dropbear/share/dropbear/meshes/torso/back-top__1__1.stl
/home/gateway/dropbear-humanoid-robot/dropbear/install/dropbear/share/dropbear/meshes/torso/rear-left-spine-support_MIR_1.stl
/home/gateway/dropbear-humanoid-robot/dropbear/install/dropbear/share/dropbear/meshes/torso/RMD-X10Rotot_1.stl
/home/gateway/dropbear-humanoid-robot/dropbear/install/dropbear/share/dropbear/meshes/torso/2020_100mm__7__1.stl
/home/gateway/dropbear-humanoid-robot/dropbear/install/dropbear/share/dropbear/meshes/torso/right-battery-mount_1.stl
/home/gateway/dropbear-humanoid-robot/dropbear/install/dropbear/share/dropbear/meshes/torso/back-bottom-strap-spine_1.stl
/home/gateway/dropbear-humanoid-robot/dropbear/install/dropbear/share/dropbear/meshes/torso/RMD-X10__1_Rotor_1.stl
/home/gateway/dropbear-humanoid-robot/dropbear/install/dropbear/share/dropbear/meshes/torso/2020_150mm__1__1.stl
/home/gateway/dropbear-humanoid-robot/dropbear/install/dropbear/share/dropbear/meshes/torso/right-shoulder-top1_1.stl
/home/gateway/dropbear-humanoid-robot/dropbear/install/dropbear/share/dropbear/meshes/torso/left-lower-rib-side_1.stl
/home/gateway/dropbear-humanoid-robot/dropbear/install/dropbear/share/dropbear/meshes/torso/right-shoulder-under1_1.stl
/home/gateway/dropbear-humanoid-robot/dropbear/install/dropbear/share/dropbear/meshes/torso/right-shoulder-under_1.stl
/home/gateway/dropbear-humanoid-robot/dropbear/install/dropbear/share/dropbear/meshes/torso/2020_200mm__6__1.stl
/home/gateway/dropbear-humanoid-robot/dropbear/install/dropbear/share/dropbear/meshes/torso/6band__2__1.stl
/home/gateway/dropbear-humanoid-robot/dropbear/install/dropbear/share/dropbear/meshes/torso/2020_100mm__6__1.stl
/home/gateway/dropbear-humanoid-robot/dropbear/install/dropbear/share/dropbear/meshes/torso/rear-right-shoulder_1.stl
/home/gateway/dropbear-humanoid-robot/dropbear/install/dropbear/share/dropbear/meshes/torso/left-middle-rib_1.stl
/home/gateway/dropbear-humanoid-robot/dropbear/install/dropbear/share/dropbear/meshes/torso/lumbar-strap_1.stl
/home/gateway/dropbear-humanoid-robot/dropbear/install/dropbear/share/dropbear/meshes/torso/2020_100mm__8__1.stl
/home/gateway/dropbear-humanoid-robot/dropbear/install/dropbear/share/dropbear/meshes/torso/2020_150mm__5__1.stl
/home/gateway/dropbear-humanoid-robot/dropbear/install/dropbear/share/dropbear/meshes/torso/rear-left-rib_1.stl
/home/gateway/dropbear-humanoid-robot/dropbear/install/dropbear/share/dropbear/meshes/torso/rear-right-shoulder_MIR_1.stl
/home/gateway/dropbear-humanoid-robot/dropbear/install/dropbear/share/dropbear/meshes/torso/back-top_1.stl
/home/gateway/dropbear-humanoid-robot/dropbear/install/dropbear/share/dropbear/meshes/torso/2020_150mm_1.stl
/home/gateway/dropbear-humanoid-robot/dropbear/install/dropbear/share/dropbear/meshes/torso/battery-monitor-holder_1.stl
/home/gateway/dropbear-humanoid-robot/dropbear/install/dropbear/share/dropbear/meshes/torso/left-battery-mount_1.stl
/home/gateway/dropbear-humanoid-robot/dropbear/install/dropbear/share/dropbear/meshes/torso/2020_200mm__9__1.stl
/home/gateway/dropbear-humanoid-robot/dropbear/install/dropbear/share/dropbear/meshes/torso/2020_150mm__4__1.stl
/home/gateway/dropbear-humanoid-robot/dropbear/install/dropbear/share/dropbear/meshes/torso/rear-right-rib_1.stl
/home/gateway/dropbear-humanoid-robot/dropbear/install/dropbear/share/dropbear/meshes/torso/right-middle-rib_1.stl
/home/gateway/dropbear-humanoid-robot/dropbear/install/dropbear/share/dropbear/meshes/torso/2020_100mm__4__1.stl
/home/gateway/dropbear-humanoid-robot/dropbear/install/dropbear/share/dropbear/meshes/torso/2020_200mm__4__1.stl
/home/gateway/dropbear-humanoid-robot/dropbear/install/dropbear/share/dropbear/meshes/torso/naval-strap__1__1.stl
/home/gateway/dropbear-humanoid-robot/dropbear/install/dropbear/share/dropbear/meshes/torso/2020_150mm__2__1.stl
/home/gateway/dropbear-humanoid-robot/dropbear/install/dropbear/share/dropbear/meshes/torso/front-left-shoulder_1.stl
/home/gateway/dropbear-humanoid-robot/dropbear/install/dropbear/share/dropbear/meshes/torso/2020_200mm__1__1.stl
/home/gateway/dropbear-humanoid-robot/dropbear/install/dropbear/share/dropbear/meshes/torso/right-lower-rib-side_1.stl
/home/gateway/dropbear-humanoid-robot/dropbear/install/dropbear/share/dropbear/meshes/torso/dumWaist_1.stl
/home/gateway/dropbear-humanoid-robot/dropbear/install/dropbear/share/dropbear/meshes/torso/right-rear-shoulder_1.stl
/home/gateway/dropbear-humanoid-robot/dropbear/install/dropbear/share/dropbear/meshes/torso/dumRightArm_1.stl
/home/gateway/dropbear-humanoid-robot/dropbear/install/dropbear/share/dropbear/meshes/rightleg/RMD-X10-S2_MIR4Stator_1.stl
/home/gateway/dropbear-humanoid-robot/dropbear/install/dropbear/share/dropbear/meshes/rightleg/RMD-X8-Pro_MIR8_MIR1_2.stl
/home/gateway/dropbear-humanoid-robot/dropbear/install/dropbear/share/dropbear/meshes/rightleg/skateboard-bearing_left_1.stl
/home/gateway/dropbear-humanoid-robot/dropbear/install/dropbear/share/dropbear/meshes/rightleg/thigh-nub_1.stl
/home/gateway/dropbear-humanoid-robot/dropbear/install/dropbear/share/dropbear/meshes/rightleg/210mm-tie-rod_v1_1.stl
/home/gateway/dropbear-humanoid-robot/dropbear/install/dropbear/share/dropbear/meshes/rightleg/flank-front__1__1.stl
/home/gateway/dropbear-humanoid-robot/dropbear/install/dropbear/share/dropbear/meshes/rightleg/calf-cover_1.stl
/home/gateway/dropbear-humanoid-robot/dropbear/install/dropbear/share/dropbear/meshes/rightleg/magmount__1__1.stl
/home/gateway/dropbear-humanoid-robot/dropbear/install/dropbear/share/dropbear/meshes/rightleg/bearingstrap_1.stl
/home/gateway/dropbear-humanoid-robot/dropbear/install/dropbear/share/dropbear/meshes/rightleg/limit-bracket-knee_1.stl
/home/gateway/dropbear-humanoid-robot/dropbear/install/dropbear/share/dropbear/meshes/rightleg/DumX290mm_1.stl
/home/gateway/dropbear-humanoid-robot/dropbear/install/dropbear/share/dropbear/meshes/rightleg/tie-rod-ankle-brackket_left1_1.stl
/home/gateway/dropbear-humanoid-robot/dropbear/install/dropbear/share/dropbear/meshes/rightleg/DumX210mm_1.stl
/home/gateway/dropbear-humanoid-robot/dropbear/install/dropbear/share/dropbear/meshes/rightleg/2020_400mm_1.stl
/home/gateway/dropbear-humanoid-robot/dropbear/install/dropbear/share/dropbear/meshes/rightleg/conjstraint-knee-test-oute_1.stl
/home/gateway/dropbear-humanoid-robot/dropbear/install/dropbear/share/dropbear/meshes/rightleg/calf-motor-driver-ext_1.stl
/home/gateway/dropbear-humanoid-robot/dropbear/install/dropbear/share/dropbear/meshes/rightleg/leg-thigh-knee-support-bottom_1.stl
/home/gateway/dropbear-humanoid-robot/dropbear/install/dropbear/share/dropbear/meshes/rightleg/new-heel_1.stl
/home/gateway/dropbear-humanoid-robot/dropbear/install/dropbear/share/dropbear/meshes/rightleg/ankle-side-bracket_2.stl
/home/gateway/dropbear-humanoid-robot/dropbear/install/dropbear/share/dropbear/meshes/rightleg/skateboard-bearing__12__1.stl
/home/gateway/dropbear-humanoid-robot/dropbear/install/dropbear/share/dropbear/meshes/rightleg/flank_1.stl
/home/gateway/dropbear-humanoid-robot/dropbear/install/dropbear/share/dropbear/meshes/rightleg/flank__1__1.stl
/home/gateway/dropbear-humanoid-robot/dropbear/install/dropbear/share/dropbear/meshes/rightleg/double-bracket-10deg_MIR_MIR_MIR_1.stl
/home/gateway/dropbear-humanoid-robot/dropbear/install/dropbear/share/dropbear/meshes/rightleg/heel-bracket_left_1.stl
/home/gateway/dropbear-humanoid-robot/dropbear/install/dropbear/share/dropbear/meshes/rightleg/basis_left_1.stl
/home/gateway/dropbear-humanoid-robot/dropbear/install/dropbear/share/dropbear/meshes/rightleg/flank-front_1.stl
/home/gateway/dropbear-humanoid-robot/dropbear/install/dropbear/share/dropbear/meshes/rightleg/2020_150mm__6__2.stl
/home/gateway/dropbear-humanoid-robot/dropbear/install/dropbear/share/dropbear/meshes/rightleg/2020_150mm__1___1__1.stl
/home/gateway/dropbear-humanoid-robot/dropbear/install/dropbear/share/dropbear/meshes/rightleg/heel-bracketleft_1.stl
/home/gateway/dropbear-humanoid-robot/dropbear/install/dropbear/share/dropbear/meshes/rightleg/bearing-sensor-adapter_2.stl
/home/gateway/dropbear-humanoid-robot/dropbear/install/dropbear/share/dropbear/meshes/rightleg/base_link.stl
/home/gateway/dropbear-humanoid-robot/dropbear/install/dropbear/share/dropbear/meshes/rightleg/RMD-X10-S2_MIR4__3_Rotor_1.stl
/home/gateway/dropbear-humanoid-robot/dropbear/install/dropbear/share/dropbear/meshes/rightleg/calf-skin_flip_1.stl
/home/gateway/dropbear-humanoid-robot/dropbear/install/dropbear/share/dropbear/meshes/rightleg/2020_300mm__1__1.stl
/home/gateway/dropbear-humanoid-robot/dropbear/install/dropbear/share/dropbear/meshes/rightleg/skateboard-bearing__15__1.stl
/home/gateway/dropbear-humanoid-robot/dropbear/install/dropbear/share/dropbear/meshes/rightleg/hip-motor-bracket-v5-right_MIR_1.stl
/home/gateway/dropbear-humanoid-robot/dropbear/install/dropbear/share/dropbear/meshes/rightleg/bearingstrap__1__1.stl
/home/gateway/dropbear-humanoid-robot/dropbear/install/dropbear/share/dropbear/meshes/rightleg/skateboard-bearing__9__1.stl
/home/gateway/dropbear-humanoid-robot/dropbear/install/dropbear/share/dropbear/meshes/rightleg/skateboard-bearing__19__1.stl
/home/gateway/dropbear-humanoid-robot/dropbear/install/dropbear/share/dropbear/meshes/rightleg/knee-strap-second-test__1__1.stl
/home/gateway/dropbear-humanoid-robot/dropbear/install/dropbear/share/dropbear/meshes/rightleg/heel-top_MIRleft_1.stl
/home/gateway/dropbear-humanoid-robot/dropbear/install/dropbear/share/dropbear/meshes/rightleg/motor-calf-exal-mount_4.stl
/home/gateway/dropbear-humanoid-robot/dropbear/install/dropbear/share/dropbear/meshes/rightleg/calf-skin_1.stl
/home/gateway/dropbear-humanoid-robot/dropbear/install/dropbear/share/dropbear/meshes/rightleg/knee-strap-second-test_1.stl
/home/gateway/dropbear-humanoid-robot/dropbear/install/dropbear/share/dropbear/meshes/rightleg/RMD-X10-S2_MIR4Rotor_1.stl
/home/gateway/dropbear-humanoid-robot/dropbear/install/dropbear/share/dropbear/meshes/rightleg/ankle-side-bracket_1.stl
/home/gateway/dropbear-humanoid-robot/dropbear/install/dropbear/share/dropbear/meshes/rightleg/leg-pitch-elastic__3__1.stl
/home/gateway/dropbear-humanoid-robot/dropbear/install/dropbear/share/dropbear/meshes/rightleg/bearing-sensor-adapter-arm_1.stl
/home/gateway/dropbear-humanoid-robot/dropbear/install/dropbear/share/dropbear/meshes/rightleg/ankle-thick_1.stl
/home/gateway/dropbear-humanoid-robot/dropbear/install/dropbear/share/dropbear/meshes/rightleg/knee-bend-motor-bracket-hip_1.stl
/home/gateway/dropbear-humanoid-robot/dropbear/install/dropbear/share/dropbear/meshes/rightleg/heel-topleft_1.stl
/home/gateway/dropbear-humanoid-robot/dropbear/install/dropbear/share/dropbear/meshes/rightleg/RMD-X8-Pro_MIR8_MIR1_1.stl
/home/gateway/dropbear-humanoid-robot/dropbear/install/dropbear/share/dropbear/meshes/rightleg/RMD-X10-S2_MIR4__3_Stator_1.stl
/home/gateway/dropbear-humanoid-robot/dropbear/install/dropbear/share/dropbear/meshes/rightleg/skateboard-bearing__14__1.stl
/home/gateway/dropbear-humanoid-robot/dropbear/install/dropbear/share/dropbear/meshes/rightleg/toes-rotor_1.stl
/home/gateway/dropbear-humanoid-robot/dropbear/install/dropbear/share/dropbear/meshes/rightleg/leg-pitch-elastic__1__1.stl
/home/gateway/dropbear-humanoid-robot/dropbear/install/dropbear/share/dropbear/meshes/rightleg/knee-bend-motor-bracket-hip__1__1.stl
/home/gateway/dropbear-humanoid-robot/dropbear/install/dropbear/share/dropbear/meshes/rightleg/heel-connector_1.stl
/home/gateway/dropbear-humanoid-robot/dropbear/install/dropbear/share/dropbear/meshes/rightleg/NO-NC_Bump_Switch_1.stl
/home/gateway/dropbear-humanoid-robot/dropbear/install/dropbear/share/dropbear/meshes/rightleg/thigh-outer-encoder-mount__1__1.stl
/home/gateway/dropbear-humanoid-robot/dropbear/install/dropbear/share/dropbear/meshes/rightleg/skateboard-bearing_1.stl
/home/gateway/dropbear-humanoid-robot/dropbear/install/dropbear/share/dropbear/meshes/rightleg/motor-calf-exal-mount_2.stl
/home/gateway/dropbear-humanoid-robot/dropbear/install/dropbear/share/dropbear/meshes/rightleg/leg-pitch-elastic_1.stl
/home/gateway/dropbear-humanoid-robot/dropbear/install/dropbear/share/dropbear/meshes/rightleg/motorcap-KNEE_MIR_1.stl
/home/gateway/dropbear-humanoid-robot/dropbear/install/dropbear/share/dropbear/meshes/rightleg/foot-imu-strap_1.stl
/home/gateway/dropbear-humanoid-robot/dropbear/install/dropbear/share/dropbear/meshes/rightleg/6band__5__1.stl
/home/gateway/dropbear-humanoid-robot/dropbear/install/dropbear/share/dropbear/meshes/rightleg/dumXrigid_1.stl
/home/gateway/dropbear-humanoid-robot/dropbear/install/dropbear/share/dropbear/meshes/rightleg/calf-lower-bracket_1.stl
/home/gateway/dropbear-humanoid-robot/dropbear/install/dropbear/share/dropbear/meshes/rightleg/2020_100mm__12__1.stl
/home/gateway/dropbear-humanoid-robot/dropbear/install/dropbear/share/dropbear/meshes/rightleg/skateboard-bearing__10__1.stl
/home/gateway/dropbear-humanoid-robot/dropbear/install/dropbear/share/dropbear/meshes/rightleg/2020_300mm__2__1.stl
/home/gateway/dropbear-humanoid-robot/dropbear/install/dropbear/share/dropbear/meshes/rightleg/hip-motor-bracket-v5-right_MIR__1__1.stl
/home/gateway/dropbear-humanoid-robot/dropbear/install/dropbear/share/dropbear/meshes/rightleg/bearing-sensor-adapter_1.stl
/home/gateway/dropbear-humanoid-robot/dropbear/install/dropbear/share/dropbear/meshes/rightleg/new-heel-opposing_1.stl
/home/gateway/dropbear-humanoid-robot/dropbear/install/dropbear/share/dropbear/meshes/rightleg/2020_150mm__6__1.stl
/home/gateway/dropbear-humanoid-robot/dropbear/install/dropbear/share/dropbear/meshes/rightleg/calf-motor-driver-ext_2.stl
/home/gateway/dropbear-humanoid-robot/dropbear/install/dropbear/share/dropbear/meshes/rightleg/mpu1_1.stl
/home/gateway/dropbear-humanoid-robot/dropbear/install/dropbear/share/dropbear/meshes/rightleg/skateboard-bearing__11__1.stl
/home/gateway/dropbear-humanoid-robot/dropbear/install/dropbear/share/dropbear/meshes/rightleg/toes_1.stl
/home/gateway/dropbear-humanoid-robot/dropbear/install/dropbear/share/dropbear/meshes/rightleg/thigh-bracket_1.stl
/home/gateway/dropbear-humanoid-robot/dropbear/install/dropbear/share/dropbear/meshes/rightleg/double-bracket_1.stl
/home/gateway/dropbear-humanoid-robot/dropbear/install/dropbear/share/dropbear/meshes/rightleg/bearingstrap-inner-thigh_1.stl
/home/gateway/dropbear-humanoid-robot/dropbear/install/dropbear/share/dropbear/meshes/rightleg/NO-NC_Bump_Switch__1__1.stl
/home/gateway/dropbear-humanoid-robot/dropbear/install/dropbear/share/dropbear/meshes/rightleg/290mm-tie-rod_v1_1.stl
/home/gateway/dropbear-humanoid-robot/dropbear/install/dropbear/share/dropbear/meshes/rightleg/skateboard-bearing__8__1.stl
/home/gateway/dropbear-humanoid-robot/dropbear/install/dropbear/share/dropbear/meshes/rightleg/ankle-motor-driver-bracket_left_1.stl
/home/gateway/dropbear-humanoid-robot/dropbear/install/dropbear/share/dropbear/meshes/rightleg/heel-roller_1.stl
/home/gateway/dropbear-humanoid-robot/dropbear/install/dropbear/share/dropbear/meshes/rightleg/skateboard-bearing_left_2.stl
/home/gateway/dropbear-humanoid-robot/dropbear/install/dropbear/share/dropbear/meshes/rightleg/calf-lower-bracket_left_1.stl
/home/gateway/dropbear-humanoid-robot/dropbear/install/dropbear/share/dropbear/meshes/rightleg/skateboard-bearing__16__1.stl
/home/gateway/dropbear-humanoid-robot/dropbear/install/dropbear/share/dropbear/meshes/rightleg/innner-thigh-magnet-encoder__1__1.stl
/home/gateway/dropbear-humanoid-robot/dropbear/install/dropbear/share/dropbear/meshes/rightleg/skateboard-bearing__18__1.stl
/home/gateway/dropbear-humanoid-robot/dropbear/install/dropbear/share/dropbear/meshes/rightleg/motor-calf-exal-mount_3.stl
/home/gateway/dropbear-humanoid-robot/dropbear/install/dropbear/share/dropbear/meshes/rightleg/skateboard-bearing__17__1.stl
/home/gateway/dropbear-humanoid-robot/dropbear/install/dropbear/share/dropbear/meshes/rightleg/skateboard-bearing__20__1.stl
/home/gateway/dropbear-humanoid-robot/dropbear/install/dropbear/share/dropbear/meshes/rightleg/knee-lock-2-b_1.stl
/home/gateway/dropbear-humanoid-robot/dropbear/install/dropbear/share/dropbear/meshes/rightleg/motor-calf-exal-mount_1.stl
/home/gateway/dropbear-humanoid-robot/dropbear/install/dropbear/share/dropbear/meshes/rightleg/skateboard-bearing__13__1.stl
/home/gateway/dropbear-humanoid-robot/dropbear/install/dropbear/share/dropbear/meshes/rightleg/flank-front-flipped_1.stl
/home/gateway/dropbear-humanoid-robot/dropbear/install/dropbear/share/dropbear/meshes/rightleg/wire-clip_1.stl
/home/gateway/dropbear-humanoid-robot/dropbear/install/dropbear/share/dropbear/meshes/rightleg/calf-cover_2.stl
/home/gateway/dropbear-humanoid-robot/dropbear/install/dropbear/share/dropbear/meshes/rightleg/bearing-sensor-adapter-arm_2.stl
/home/gateway/dropbear-humanoid-robot/dropbear/install/dropbear/share/dropbear/meshes/rightleg/leg-pitch-elastic__2__1.stl
/home/gateway/dropbear-humanoid-robot/dropbear/install/dropbear/share/dropbear/meshes/rightleg/conjstraint-knee-test-oute_MIR_1.stl
/home/gateway/dropbear-humanoid-robot/dropbear/install/dropbear/share/dropbear/meshes/rightleg/400mmexal_MIR2_MIR3_1.stl
/home/gateway/dropbear-humanoid-robot/dropbear/install/dropbear/share/dropbear/meshes/rightleg/ankle-motor-driver-bracketleft_1.stl
/home/gateway/dropbear-humanoid-robot/dropbear/install/dropbear/share/dropbear/meshes/rightleg/foot-top_1.stl
/home/gateway/dropbear-humanoid-robot/dropbear/install/dropbear/share/dropbear/meshes/rightleg/hip-ex-al-base_MIR_1.stl
/home/gateway/dropbear-humanoid-robot/dropbear/install/dropbear/share/dropbear/meshes/rightleg/multiplex-stack_1.stl
/home/gateway/dropbear-humanoid-robot/dropbear/install/dropbear/share/dropbear/meshes/rightleg/tie-rod-ankle-brackket_left_1.stl
/home/gateway/dropbear-humanoid-robot/dropbear/install/dropbear/share/dropbear/rviz/dropbear_detailed_urdf_rviz.rviz
/home/gateway/dropbear-humanoid-robot/dropbear/install/dropbear/share/dropbear/rviz/dropbear_rviz.rviz
/home/gateway/dropbear-humanoid-robot/dropbear/install/dropbear/share/dropbear/urdf/rviz/arm.xacro
/home/gateway/dropbear-humanoid-robot/dropbear/install/dropbear/share/dropbear/urdf/rviz/leg.xacro
/home/gateway/dropbear-humanoid-robot/dropbear/install/dropbear/share/dropbear/urdf/rviz/pelvicgirdle.xacro
/home/gateway/dropbear-humanoid-robot/dropbear/install/dropbear/share/dropbear/urdf/rviz/dropbear.urdf.xacro
/home/gateway/dropbear-humanoid-robot/dropbear/install/dropbear/share/dropbear/urdf/rviz/head.xacro
/home/gateway/dropbear-humanoid-robot/dropbear/install/dropbear/share/dropbear/urdf/rviz/battery.xacro
/home/gateway/dropbear-humanoid-robot/dropbear/install/dropbear/share/dropbear/urdf/rviz/torso.xacro
/home/gateway/dropbear-humanoid-robot/dropbear/install/dropbear/share/dropbear/urdf/materials.xacro
/home/gateway/dropbear-humanoid-robot/dropbear/install/dropbear/share/dropbear/urdf/ros2_control/leg.ros2_control.xacro
/home/gateway/dropbear-humanoid-robot/dropbear/install/dropbear/share/dropbear/urdf/ros2_control/dropbear.macro.xacro
/home/gateway/dropbear-humanoid-robot/dropbear/install/dropbear/share/dropbear/urdf/ros2_control/stewart_platform.ros2_control.xacro
/home/gateway/dropbear-humanoid-robot/dropbear/install/dropbear/share/dropbear/urdf/ros2_control/dropbear.ros2_control.xacro
/home/gateway/dropbear-humanoid-robot/dropbear/install/dropbear/share/dropbear/urdf/ros2_control/arm.ros2_control.xacro
/home/gateway/dropbear-humanoid-robot/dropbear/install/dropbear/share/dropbear/urdf/ros2_control/pelvicgirdle.ros2_control.xacro
/home/gateway/dropbear-humanoid-robot/dropbear/install/dropbear/share/dropbear/urdf/gazebo/arm.xacro
/home/gateway/dropbear-humanoid-robot/dropbear/install/dropbear/share/dropbear/urdf/gazebo/leg.xacro
/home/gateway/dropbear-humanoid-robot/dropbear/install/dropbear/share/dropbear/urdf/gazebo/pelvicgirdle.xacro
/home/gateway/dropbear-humanoid-robot/dropbear/install/dropbear/share/dropbear/urdf/gazebo/dropbear_gz.urdf.xacro
/home/gateway/dropbear-humanoid-robot/dropbear/install/dropbear/share/dropbear/urdf/gazebo/dropbear.sdf
/home/gateway/dropbear-humanoid-robot/dropbear/install/dropbear/share/dropbear/urdf/gazebo/head.xacro
/home/gateway/dropbear-humanoid-robot/dropbear/install/dropbear/share/dropbear/urdf/gazebo/dropbear_gz.urdf
/home/gateway/dropbear-humanoid-robot/dropbear/install/dropbear/share/dropbear/urdf/gazebo/battery.xacro
/home/gateway/dropbear-humanoid-robot/dropbear/install/dropbear/share/dropbear/urdf/gazebo/p.xacro
/home/gateway/dropbear-humanoid-robot/dropbear/install/dropbear/share/dropbear/urdf/gazebo/torso.xacro
/home/gateway/dropbear-humanoid-robot/dropbear/install/dropbear/share/dropbear/config/controllers.yaml
/home/gateway/dropbear-humanoid-robot/dropbear/install/dropbear/share/ament_index/resource_index/package_run_dependencies/dropbear
/home/gateway/dropbear-humanoid-robot/dropbear/install/dropbear/share/ament_index/resource_index/parent_prefix_path/dropbear
/home/gateway/dropbear-humanoid-robot/dropbear/install/dropbear/share/dropbear/environment/ament_prefix_path.sh
/home/gateway/dropbear-humanoid-robot/dropbear/install/dropbear/share/dropbear/environment/ament_prefix_path.dsv
/home/gateway/dropbear-humanoid-robot/dropbear/install/dropbear/share/dropbear/environment/path.sh
/home/gateway/dropbear-humanoid-robot/dropbear/install/dropbear/share/dropbear/environment/path.dsv
/home/gateway/dropbear-humanoid-robot/dropbear/install/dropbear/share/dropbear/local_setup.bash
/home/gateway/dropbear-humanoid-robot/dropbear/install/dropbear/share/dropbear/local_setup.sh
/home/gateway/dropbear-humanoid-robot/dropbear/install/dropbear/share/dropbear/local_setup.zsh
/home/gateway/dropbear-humanoid-robot/dropbear/install/dropbear/share/dropbear/local_setup.dsv
/home/gateway/dropbear-humanoid-robot/dropbear/install/dropbear/share/dropbear/package.dsv
/home/gateway/dropbear-humanoid-robot/dropbear/install/dropbear/share/ament_index/resource_index/packages/dropbear
/home/gateway/dropbear-humanoid-robot/dropbear/install/dropbear/share/dropbear/cmake/dropbearConfig.cmake
/home/gateway/dropbear-humanoid-robot/dropbear/install/dropbear/share/dropbear/cmake/dropbearConfig-version.cmake
/home/gateway/dropbear-humanoid-robot/dropbear/install/dropbear/share/dropbear/package.xml

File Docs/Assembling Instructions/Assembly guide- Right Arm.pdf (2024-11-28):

# Step by Step

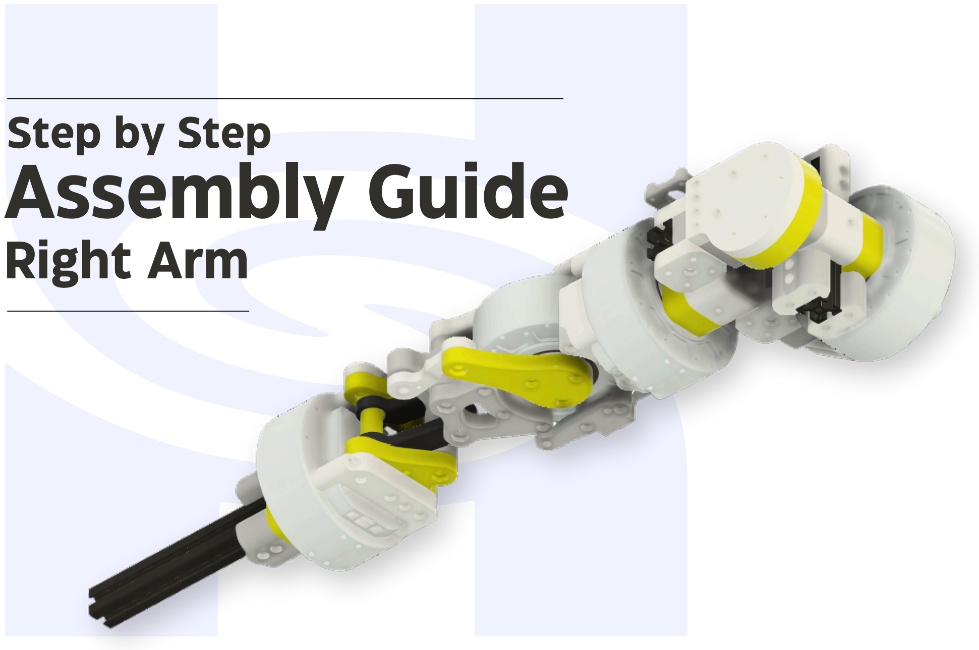
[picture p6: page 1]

# Right Arm

# Assembly Guide

## Fasteners M4 x 16 mm = 4 Qty

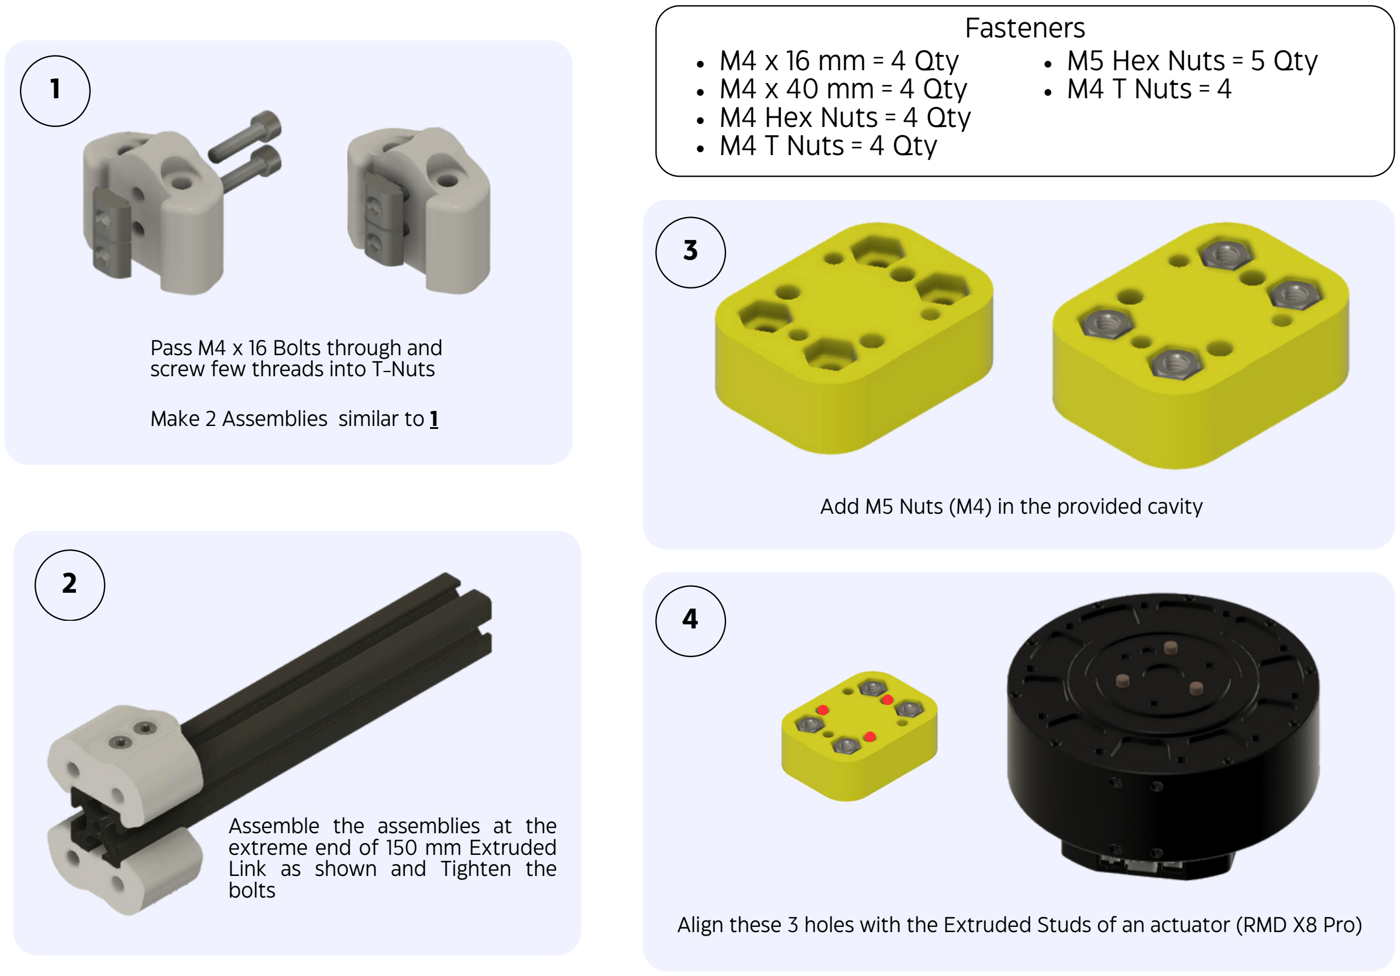
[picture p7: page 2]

## M4 x 40 mm = 4 Qty M4 Hex Nuts = 4 Qty M4 T Nuts = 4 Qty

## M5 Hex Nuts = 5 Qty M4 T Nuts = 4

Assemble the assemblies at the extreme end of 150 mm Extruded Link as shown and Tighten the bolts

1

2

3

4

Add M5 Nuts (M4) in the provided cavity

Align these 3 holes with the Extruded Studs of an actuator (RMD X8 Pro)

Pass M4 x 16 Bolts through and screw few threads into T-Nuts

Make 2 Assemblies similar to 1

5

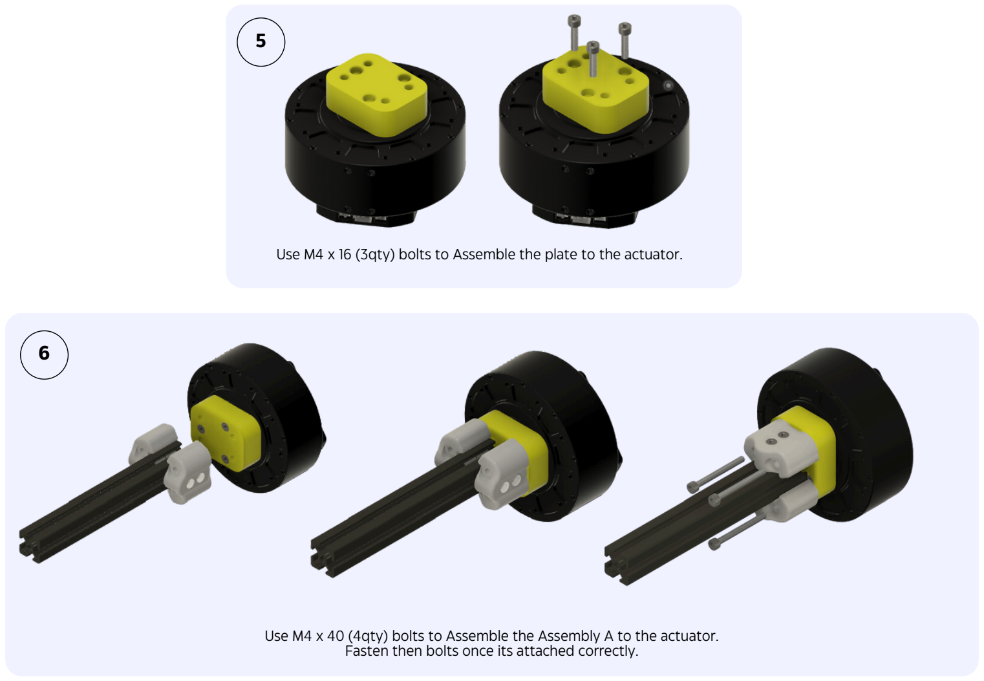
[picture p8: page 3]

Use M4 x 16 (3qty) bolts to Assemble the plate to the actuator.

Use M4 x 40 (4qty) bolts to Assemble the Assembly A to the actuator. Fasten then bolts once its attached correctly.

6

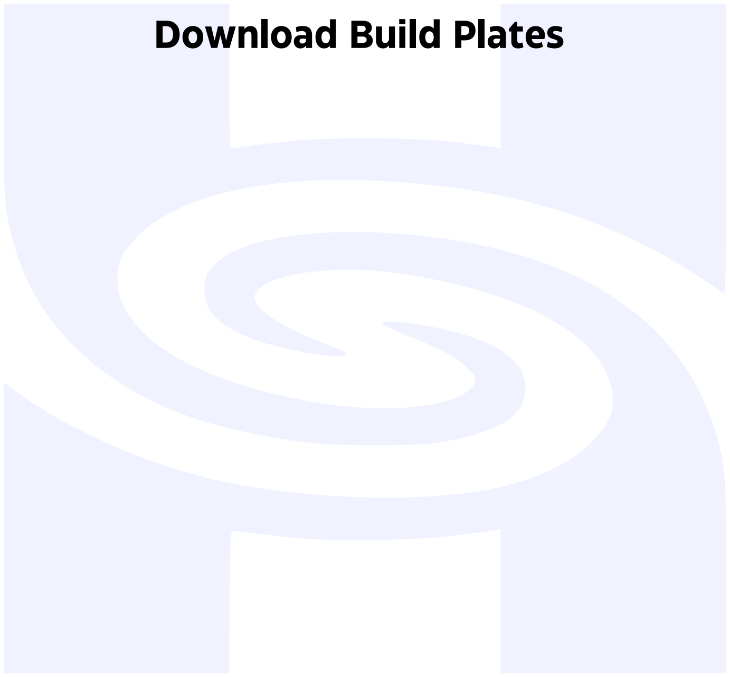
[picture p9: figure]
Download Build Plates

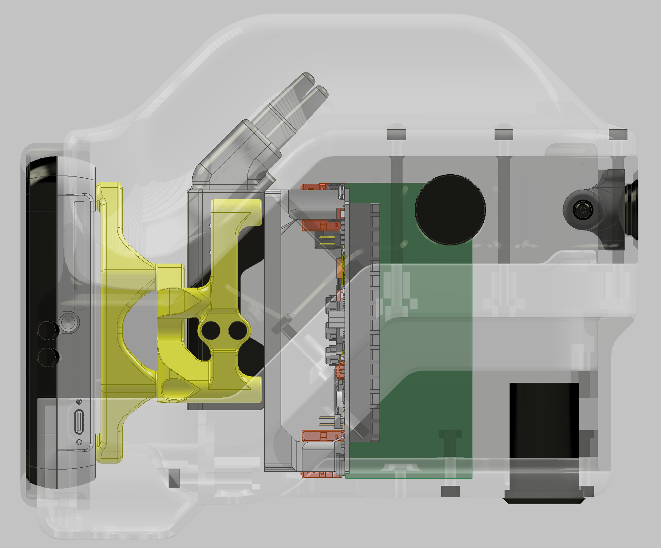
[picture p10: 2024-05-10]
CAD_Files/Assembly/Head/INTERNAL_ASSEMBLY/IMAGES/profile.PNG

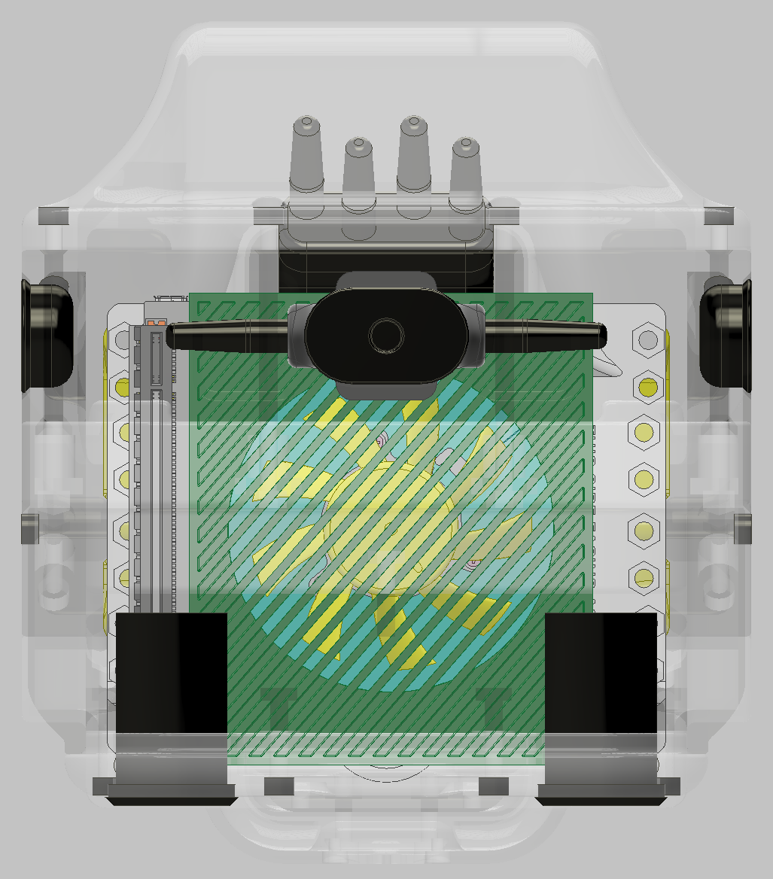
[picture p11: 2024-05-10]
CAD_Files/Assembly/Head/INTERNAL_ASSEMBLY/IMAGES/rear.PNG

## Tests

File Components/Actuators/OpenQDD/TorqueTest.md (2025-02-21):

# QDD Actuator Torque Calculation

## Overview
This document outlines the torque calculation for a **Quasi-Direct Drive (QDD) Actuator** based on experimental measurements.

## Calculation Details

### **Given Data**
- **Length of link:** `0.37m` (from center)
- **Mass on weighing scale:** `2.4 kg`
- **Gravitational acceleration:** `g = 9.81 m/s²`

### **Force Calculation**
Force due to gravity is given by:

```
F = m × g
```

Substituting the values:

```
F = 2.4 × 9.81
F = 23.54 N
```

### **Torque Calculation**
Torque is calculated using:

```
T = F × r
```

Substituting the values:

```
T = 23.54 × 0.37
T = 8.709 N·m
```

### **Final Result:**
**Torque (T) = `8.709 N·m`**

---

## **Test Conditions**
- **Voltage applied:** `31V`
- **Current drawn:** `10A`

These values represent the conditions under which the actuator was tested.

---

## **Notes**
- The torque was calculated based on a static weight measurement.
- Dynamic effects, back-EMF, and motor efficiency were not considered in this calculation.

---

## **Contributing**
If you find any errors or have suggestions for improvements, feel free to open a pull request!

---

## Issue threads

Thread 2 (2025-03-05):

Error load meshes .STL in RViz & Gazebo

LuisYordano, 2025-03-05:
Hi, Team Hyperspawn.

I am testing RViz and Gazebo. When running the command: **ros2 launch dropbear_simplified_urdf dropbear_rviz.launch.py**

In RViz, Nothing can be displayed:

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

In Meshlab I can't see the .STL files:

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

Could you re-upload all .STL files?

I thank you in advance.

UNICORN-2887, 2025-08-01:
bro i notice your icon that we all are gundam builder ：）

UNICORN-2887, 2025-08-22:
yet, I fond an replace method, when I trying simulate, I discovery some stl files here: https://github.com/Hyperspawn/dropbear_urdf/tree/main
it contains the models files and urdf files,
but i hasnt assemble, you can view the assemble photo in "media" repository.

hope can help u)

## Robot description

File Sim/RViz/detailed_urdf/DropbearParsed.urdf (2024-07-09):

<?xml version="1.0" ?>
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
<robot xmlns:xacro="http://www.ros.org/wiki/xacro" name="humanoid">
  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
  <link name="torso">
    <inertial>
      <origin xyz="-0.03675640917673825 0.10469671997794947 0.060052559811593326" rpy="0 0 0"/>
      <mass value="3.2595669741313733"/>
      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
    </inertial>
    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
  </link>
  <link name="DumHead_1">
    <inertial>
      <origin xyz="-3.751708517185648e-07 0.0024995864992679723 -3.670208372427708e-07" rpy="0 0 0"/>
      <mass value="0.01082462598101003"/>
      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
    </inertial>
    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
  </link>
  <joint name="Rigid 7" type="fixed">
    <origin xyz="0.078519 0.116226 0.059747" rpy="0 0 0"/>
    <parent link="torso"/>
    <child link="DumHead_1"/>
  </joint>
  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
  <link name="sim_world"/>
  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
  <joint name="base_link_sim_world_joint" type="fixed">
    <origin xyz="0.0 0.0 1.2" rpy="1.5707965 0.0 0.0"/>
    <parent link="sim_world"/>
    <child link="torso"/>
  </joint>
  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
  <link name="Rotate-right-leg_1">
    <inertial>
      <origin xyz="0.06120754854285463 -0.0029503876001564233 0.014756359444244638" rpy="0 0 0"/>
      <mass value="0.5634737106043444"/>
      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
    </inertial>
    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
  </link>
  <link name="Rotate-left-leg_1">
    <inertial>
      <origin xyz="0.06120127554004958 -0.0029502323515913087 -0.014767579628205085" rpy="0 0 0"/>
      <mass value="0.563679151820761"/>
      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
    </inertial>
    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
  </link>
  <link name="Left-femur-top_1">
    <inertial>
      <origin xyz="-4.097892786209326e-06 -0.04138743736457201 0.004860837445485772" rpy="0 0 0"/>
      <mass value="0.17034196336973478"/>
      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
    </inertial>
    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
  </link>
  <link name="Right-femur-top_1">
    <inertial>
      <origin xyz="-1.1875230248842295e-05 -0.04016954723293298 -0.005717104429115966" rpy="0 0 0"/>
      <mass value="0.17742927672123618"/>
      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
    </inertial>
    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
  </link>
  <link name="DumRightLeg_1">
    <inertial>
      <origin xyz="-2.719365716774558e-07 -0.00043367314179110217 0.002461581106896815" rpy="0 0 0"/>
      <mass value="0.06889197528787226"/>
      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
    </inertial>
    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
  </link>
  <link name="DumLeftLeg_1">
    <inertial>
      <origin xyz="6.474975373111508e-07 -0.00043367314397685375 -0.0024621363755123714" rpy="0 0 0"/>
      <mass value="0.06889197549127557"/>
      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
    </inertial>
    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
  </link>
  <link name="Buttocks_1">
    <inertial>
      <origin xyz="0.07123027976226544 -0.05736392763598394 1.174722519241278e-05" rpy="0 0 0"/>
      <mass value="0.9540709404154066"/>
      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
    </inertial>
    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
  </link>
  <joint name="right_leg_pitch" type="continuous">
    <origin xyz="0.034981 -0.092175 0.061009" rpy="0 0 0"/>
    <parent link="Buttocks_1"/>
    <child link="Rotate-right-leg_1"/>
    <axis xyz="1.0 -3.2e-05 0.000261"/>
  </joint>
  <joint name="left_leg_pitch" type="continuous">
    <origin xyz="0.035013 -0.092175 -0.060991" rpy="0 0 0"/>
    <parent link="Buttocks_1"/>
    <child link="Rotate-left-leg_1"/>
    <axis xyz="1.0 -3.2e-05 0.000261"/>
  </joint>
  <joint name="left_leg_yaw" type="continuous">
    <origin xyz="0.112901 -0.021262 -0.005361" rpy="0 0 0"/>
    <parent link="Rotate-left-leg_1"/>
    <child link="Left-femur-top_1"/>
    <axis xyz="-7.7e-05 -0.984808 0.173648"/>
  </joint>
  <joint name="right_leg_yaw" type="continuous">
    <origin xyz="0.112898 -0.021262 0.00542" rpy="0 0 0"/>
    <parent link="Rotate-right-leg_1"/>
    <child link="Right-femur-top_1"/>
    <axis xyz="1.4e-05 -0.984808 -0.173648"/>
  </joint>
  <joint name="Connection_to_R_leg" type="fixed">
    <origin xyz="-7e-06 -0.074639 0.017302" rpy="0 0 0"/>
    <parent link="Right-femur-top_1"/>
    <child link="DumRightLeg_1"/>
  </joint>
  <joint name="Connection_to_L_leg" type="fixed">
    <origin xyz="2e-06 -0.074639 -0.017302" rpy="0 0 0"/>
    <parent link="Left-femur-top_1"/>
    <child link="DumLeftLeg_1"/>
  </joint>
  <joint name="torso_connection" type="fixed">
    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
    <origin xyz="-0.140001 -0.171194 0.05969" rpy="0 0 0"/>
    <parent link="torso"/>
    <child link="Buttocks_1"/>
  </joint>
  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
  <link name="RH_2020_100mm__9__1">
    <inertial>
      <origin xyz="1.4980442800229068e-14 5.199887469533773e-15 0.049999999999999795" rpy="0 0 0"/>
      <mass value="0.01959174744456203"/>
      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
    </inertial>
    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
  </link>
  <link name="RH_shoulder-roll-al-mot_MIR1__1__1">
    <inertial>
      <origin xyz="0.005127204279605231 -0.01578027268886943 0.013349013943228552" rpy="0 0 0"/>
      <mass value="0.013982280562432234"/>
      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
    </inertial>
    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
  </link>
  <link name="RH_shoulder-roll-al-mot_MIR1__2__1">
    <inertial>
      <origin xyz="-0.005127204279607458 0.015780272688869185 0.013349013943228556" rpy="0 0 0"/>
      <mass value="0.013982280562432234"/>
      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
    </inertial>
    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
  </link>
  <link name="RH_yaw-cap_1">
    <inertial>
      <origin xyz="-8.404754804490673e-15 2.1068804545096473e-14 -0.006586829858195878" rpy="0 0 0"/>
      <mass value="0.01479708114860003"/>
      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
    </inertial>
    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
  </link>
  <link name="RH_yaw-waist-adapter-motor-exal_MIR1_1">
    <inertial>
      <origin xyz="-0.0022354396247523025 0.006879975731446575 0.049999999999987436" rpy="0 0 0"/>
      <mass value="0.03741323772199936"/>
      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
    </inertial>
    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
  </link>
  <link name="RH_front-bearing-adapter-shoulder_1">
    <inertial>
      <origin xyz="0.012476625956564928 0.01204671407588206 -0.00900000000002072" rpy="0 0 0"/>
      <mass value="0.023683107739144046"/>
      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
    </inertial>
    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
  </link>
  <link name="RH_shoulder-ex-al-interface__2__1">
    <inertial>
      <origin xyz="0.01738138579865837 -0.0030497886170603797 -0.008999999999991598" rpy="0 0 0"/>
      <mass value="0.027893677646265"/>
      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
    </inertial>
    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
  </link>
  <link name="RH_RMD-X8-Pro_MIR8_MIR1__1__1">
    <inertial>
      <origin xyz="0.0067650965649745445 -0.020808521702550438 0.00046176070349858434" rpy="0 0 0"/>
      <mass value="0.06584099967983092"/>
      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
    </inertial>
    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
  </link>
  <link name="RH_shoulder-motor-bicep-rotor-bracket_1">
    <inertial>
      <origin xyz="0.011585383104448774 -0.002019144805998477 0.006894585665480131" rpy="0 0 0"/>
      <mass value="0.02426318714404453"/>
      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
    </inertial>
    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
  </link>
  <link name="RH_bicep-rear-motor-adapter_1">
    <inertial>
      <origin xyz="-0.0018929355342764131 0.016127672677199507 0.015500000000001603" rpy="0 0 0"/>
      <mass value="0.028168122670994413"/>
      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
    </inertial>
    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
  </link>
  <link name="RH_bicep-shoulder-bracket-exal__1__1">
    <inertial>
      <origin xyz="0.011983042446585573 -0.004518260205938709 0.005535150009386286" rpy="0 0 0"/>
      <mass value="0.011900029993668276"/>
      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
    </inertial>
    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
  </link>
  <link name="RH_bicep-shoulder-bracket-exal__2__1">
    <inertial>
      <origin xyz="0.011983042446582756 -0.004518260205939313 -0.0054648499906134115" rpy="0 0 0"/>
      <mass value="0.011900029993668276"/>
      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
    </inertial>
    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
  </link>
  <link name="RH_2020_100mm__8__1">
    <inertial>
      <origin xyz="-0.02187147869637933 0.034952359549973555 -0.009999999999981746" rpy="0 0 0"/>
      <mass value="0.01959174744456203"/>
      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
    </inertial>
    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
  </link>
  <link name="RH_yaw-waist-adapter-motor-exal_MIR1__5__1">
    <inertial>
      <origin xyz="0.008570545572160838 -0.049788080074744674 1.457167719820518e-15" rpy="0 0 0"/>
      <mass value="0.03741323772199936"/>
      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
    </inertial>
    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
  </link>
  <link name="RH_bicep-shoulder-bracket-exal_1">
    <inertial>
      <origin xyz="-0.014231130165287431 -0.020921360581575885 -0.007214849990613441" rpy="0 0 0"/>
      <mass value="0.011900029993668276"/>
      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
    </inertial>
    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
  </link>
  <link name="RH_shoulder-front_1">
    <inertial>
      <origin xyz="-0.007463364992977992 -0.010559925065031256 0.010000000000000855" rpy="0 0 0"/>
      <mass value="0.0285901454621081"/>
      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
    </inertial>
    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
  </link>
  <link name="RH_bicep-shoulder-bracket-exal__3__1">
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

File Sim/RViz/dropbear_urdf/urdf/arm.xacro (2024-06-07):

<?xml version="1.0" ?>
<robot name="humanoidrightarm" xmlns:xacro="http://www.ros.org/wiki/xacro">

  <xacro:macro name="arm_macro" params="prefix folder parent sign *origin">
    
    <link name="${prefix}_2020_100mm__9__1">
      <inertial>
        <origin xyz="1.4980442800229068e-14 5.199887469533773e-15 ${sign*0.049999999999999795}" rpy="0 0 0"/>
        <mass value="0.01959174744456203"/>
        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
      </inertial>
      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
    </link>
    
    <link name="${prefix}_shoulder-roll-al-mot_MIR1__1__1">
      <inertial>
        <origin xyz="0.005127204279605231 -0.01578027268886943 ${sign*0.013349013943228552}" rpy="0 0 0"/>
        <mass value="0.013982280562432234"/>
        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
      </inertial>
      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
    </link>
    
    <link name="${prefix}_shoulder-roll-al-mot_MIR1__2__1">
      <inertial>
        <origin xyz="-0.005127204279607458 0.015780272688869185 ${sign*0.013349013943228556}" rpy="0 0 0"/>
        <mass value="0.013982280562432234"/>
        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
      </inertial>
      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
    </link>
    
    <link name="${prefix}_yaw-cap_1">
      <inertial>
        <origin xyz="-8.404754804490673e-15 2.1068804545096473e-14 ${sign*-0.006586829858195878}" rpy="0 0 0"/>
        <mass value="0.01479708114860003"/>
        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
      </inertial>
      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
    </link>
    
    <link name="${prefix}_yaw-waist-adapter-motor-exal_MIR1_1">
      <inertial>
        <origin xyz="-0.0022354396247523025 0.006879975731446575 ${sign*0.049999999999987436}" rpy="0 0 0"/>
        <mass value="0.03741323772199936"/>
        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
      </inertial>
      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
    </link>
    
    <link name="${prefix}_front-bearing-adapter-shoulder_1">
      <inertial>
        <origin xyz="0.012476625956564928 0.01204671407588206 ${sign*-0.00900000000002072}" rpy="0 0 0"/>
        <mass value="0.023683107739144046"/>
        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
      </inertial>
      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
    </link>
    
    <link name="${prefix}_shoulder-ex-al-interface__2__1">
      <inertial>
        <origin xyz="0.01738138579865837 -0.0030497886170603797 ${sign*-0.008999999999991598}" rpy="0 0 0"/>
        <mass value="0.027893677646265"/>
        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
      </inertial>
      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
    </link>
    
    <link name="${prefix}_RMD-X8-Pro_MIR8_MIR1__1__1">
      <inertial>
        <origin xyz="0.0067650965649745445 -0.020808521702550438 ${sign*0.00046176070349858434}" rpy="0 0 0"/>
        <mass value="0.06584099967983092"/>
        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
      </inertial>
      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
    </link>
    
    <link name="${prefix}_shoulder-motor-bicep-rotor-bracket_1">
      <inertial>
        <origin xyz="0.011585383104448774 -0.002019144805998477 ${sign*0.006894585665480131}" rpy="0 0 0"/>
        <mass value="0.02426318714404453"/>
        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
      </inertial>
      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
    </link>
    
    <link name="${prefix}_bicep-rear-motor-adapter_1">
      <inertial>
        <origin xyz="-0.0018929355342764131 0.016127672677199507 ${sign*0.015500000000001603}" rpy="0 0 0"/>
        <mass value="0.028168122670994413"/>
        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
      </inertial>
      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
    </link>
    
    <link name="${prefix}_bicep-shoulder-bracket-exal__1__1">
      <inertial>
        <origin xyz="0.011983042446585573 -0.004518260205938709 ${sign*0.005535150009386286}" rpy="0 0 0"/>
        <mass value="0.011900029993668276"/>
        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
      </inertial>
      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
    </link>
    
    <link name="${prefix}_bicep-shoulder-bracket-exal__2__1">
      <inertial>
        <origin xyz="0.011983042446582756 -0.004518260205939313 ${sign*-0.0054648499906134115}" rpy="0 0 0"/>
        <mass value="0.011900029993668276"/>
        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
      </inertial>
      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
    </link>
    
    <link name="${prefix}_2020_100mm__8__1">
      <inertial>
        <origin xyz="-0.02187147869637933 0.034952359549973555 ${sign*-0.009999999999981746}" rpy="0 0 0"/>
        <mass value="0.01959174744456203"/>
        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
      </inertial>
      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
    </link>
    
    <link name="${prefix}_yaw-waist-adapter-motor-exal_MIR1__5__1">
      <inertial>
        <origin xyz="0.008570545572160838 -0.049788080074744674 ${sign*1.457167719820518e-15}" rpy="0 0 0"/>
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

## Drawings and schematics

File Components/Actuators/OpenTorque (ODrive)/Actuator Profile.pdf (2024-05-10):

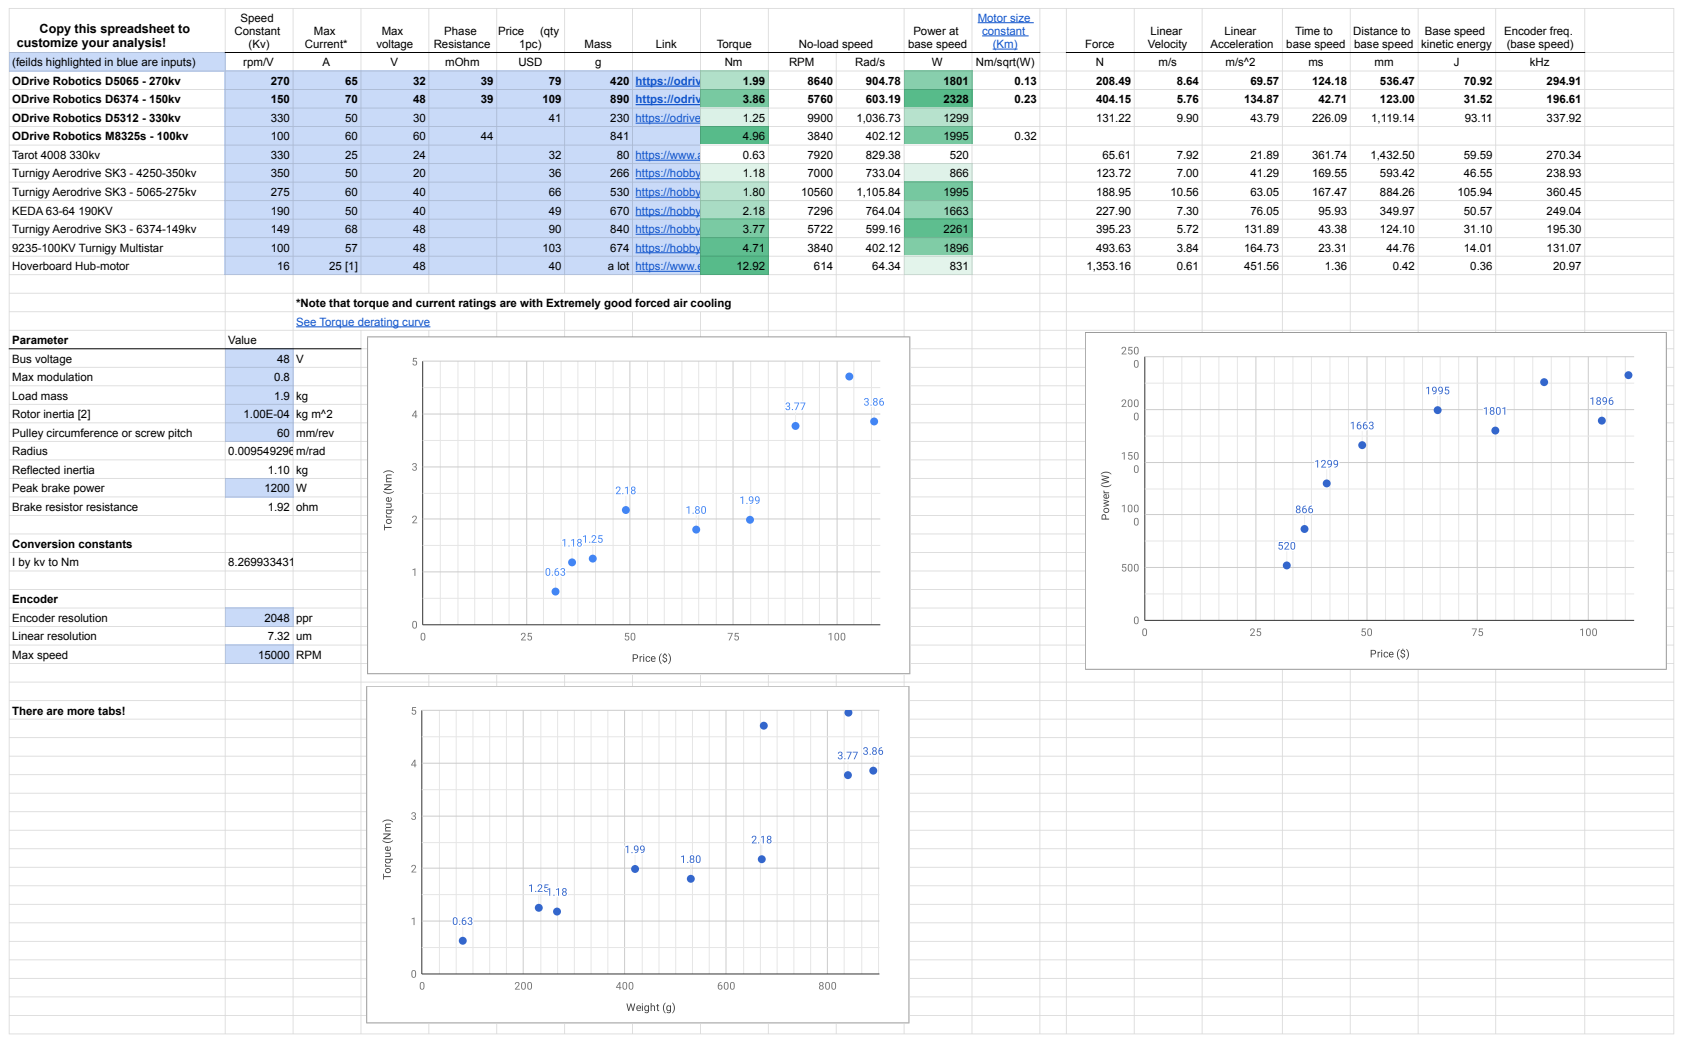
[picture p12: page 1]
Speed Constant; Max Current*; Max voltage; Phase Resistance; Price; (qty; Mass; Link; Torque; No-load speed; Power at base speed; Motor size constant; Force; Linear Velocity; Linear Acceleration; Time to base speed; Distance to base speed; Base speed kinetic energy; Encoder freq. (base speed); (feilds highlighted in blue are inputs); rpm/V; mOhm; USD; RPM; Rad/s; Nm/sqrt(W); kHz; ODrive Robotics D5065 - 270kv; 420 https://odriverobotics.com/shop/odrive-custom-motor-d5065 1.99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

Copy this spreadsheet to
customize your analysis! 📚📐📏

*Note that torque and current ratings are with Extremely good forced air cooling
See Torque derating curve

There are more tabs!

# [1] Assuming improved cooling mod

[2] Note: We should measure inertia of each individual motor. This is an estimate of 5065 size motors.

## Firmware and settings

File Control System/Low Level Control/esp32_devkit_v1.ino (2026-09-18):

#include <Arduino.h>
#include <mcp_can.h>
#include <SPI.h>
#include <SPIFFS.h>
#include <Wire.h>
#include <WiFi.h>
#include <WebServer.h>
#include <DNSServer.h>
#include <stdarg.h>
#include <freertos/FreeRTOS.h>
#include <freertos/task.h>
#include <freertos/semphr.h>
#include <math.h>

/*
 * Dropbear ESP32 low-level leg controller
 *
 * Updated architecture:
 *   - Preserves existing ESP32 MCP2515/SPI and I2C pinout.
 *   - Portal-enabled builds move joint sensors to ADC1 GPIOs because classic
 *     ESP32 ADC2 channels cannot be used reliably while Wi-Fi is active.
 *   - Preserves MyActuator CAN IDs 0x141..0x14C.
 *   - Preserves A1 torque-control and 0x81 stop commands.
 *   - Uses one periodic CAN-output task as the normal actuator writer.
 *   - Impedance task computes desired torque only; it does not transmit CAN.
 *   - Each leg controller transmits only to its selected chirality (6 motors).
 *   - Correct stop commands use actual actuator CAN IDs.
 *   - Calibration uses an output override instead of racing the CAN task.
 *   - Fixes impedance serial parsing and joint-constraint persistence.
 *   - Starts the IMU task in center mode.
 *   - Sensor acquisition remains 1 kHz; serial telemetry is throttled to 50 Hz.
 *   - External sensors establish the restart reference; continuous RMD 0x92
 *     feedback supplies measured motor position after zeroing.
 *   - Adds role-aware Wi-Fi SoftAP + captive portal control/configuration.
 *   - LEFTLEG / RIGHTLEG / CENTER SSID follows persisted chirality.
 *   - Existing SPIFFS configuration is loaded into the web configurator.
 *   - Web commands are queued into the same parser used by USB Serial.
 *   - Live state, command log, config, and SPIFFS inspection are exposed locally.
 */

static const char *DROPBEAR_FIRMWARE_VERSION =
  "legacy-v1-observation-protocol-2026.09.18";
static const char *DROPBEAR_COMMAND_PROTOCOL = "LEGACY";
static const char *DROPBEAR_TELEMETRY_PROTOCOL = "DB3";
static const char *DROPBEAR_CAPABILITIES =
  "version-v1;health-v1;observe-stream-v1;motor-angle-rmd-v17-v42-0x92;"
  "motor-control-aligned-v1;as5600-crosscheck-v1;legacy-portal";

// -----------------------------------------------------------------------------
// Hardware
// -----------------------------------------------------------------------------

#define I2C_SDA_PIN 21
#define I2C_SCL_PIN 22
#define CAN_CS_PIN 5
#define CAN0_INT GPIO_NUM_17

#define SPI_SCK_PIN 18
#define SPI_MISO_PIN 19
#define SPI_MOSI_PIN 23

#define IMU_COUNT 5

MCP_CAN CAN(CAN_CS_PIN);

// Full-time Wi-Fi and ESP32 ADC2 cannot coexist on classic ESP32.
// Portal-enabled builds therefore use only ADC1 sensor inputs.
//
// WIFI-SAFE ADC1 PINOUT (default):
//   outer calf  -> GPIO32  ADC1_CH4
//   inner calf  -> GPIO34  ADC1_CH6
//   hip pitch   -> GPIO35  ADC1_CH7
//   knee        -> GPIO36  ADC1_CH0
//   hip roll    -> GPIO33  ADC1_CH5
//
// LEGACY DROPBEAR PINOUT:
//   14,27,26,25,33. GPIO14/25/26/27 are ADC2 and are not safe while
//   Wi-Fi is active on classic ESP32.
//
// Set to 0 only if retaining the legacy wiring; doing so disables the Wi-Fi
// captive portal at runtime so ADC2 sensing remains valid.
#define DROPBEAR_ENABLE_WIFI_PORTAL 1

#if DROPBEAR_ENABLE_WIFI_PORTAL
static const int PIN_OUTER_CALF = 32;
static const int PIN_INNER_CALF = 34;
static const int PIN_HIP_PITCH = 35;
static const int PIN_KNEE = 36;
static const int PIN_HIP_ROLL = 33;
#else
static const int PIN_OUTER_CALF = 14;
static const int PIN_INNER_CALF = 27;
static const int PIN_HIP_PITCH = 26;
static const int PIN_KNEE = 25;
static const int PIN_HIP_ROLL = 33;
#endif

// -----------------------------------------------------------------------------
// Actuator mapping
// Index ordering intentionally preserves the original torqueValues[] mapping:
// even indexes = right leg, odd indexes = left leg.
// -----------------------------------------------------------------------------

enum ActuatorIndex : uint8_t {
  RIGHT_OUTER_CALF = 0,
  LEFT_OUTER_CALF = 1,
  RIGHT_INNER_CALF = 2,
  LEFT_INNER_CALF = 3,
  RIGHT_KNEE = 4,
  LEFT_KNEE = 5,
  RIGHT_HIP_PITCH = 6,
  LEFT_HIP_PITCH = 7,
  RIGHT_HIP_YAW = 8,
  LEFT_HIP_YAW = 9,
  RIGHT_HIP_ROLL = 10,
  LEFT_HIP_ROLL = 11,
  ACTUATOR_COUNT = 12
};

static const uint32_t ACTUATOR_IDS[ACTUATOR_COUNT] = {
  0x144, // right outer calf
  0x141, // left outer calf
  0x143, // right inner calf
  0x142, // left inner calf
  0x148, // right knee
  0x145, // left knee
  0x147, // right hip pitch
  0x146, // left hip pitch
  0x14C, // right hip yaw
  0x149, // left hip yaw
  0x14B, // right hip roll
  0x14A  // left hip roll
};

// Backward-compatible named constants.
const unsigned long ACTUATOR_ID_RIGHT_CALF_OUTER = ACTUATOR_IDS[RIGHT_OUTER_CALF];
const unsigned long ACTUATOR_ID_LEFT_CALF_OUTER = ACTUATOR_IDS[LEFT_OUTER_CALF];
const unsigned long ACTUATOR_ID_RIGHT_CALF_INNER = ACTUATOR_IDS[RIGHT_INNER_CALF];
const unsigned long ACTUATOR_ID_LEFT_CALF_INNER = ACTUATOR_IDS[LEFT_INNER_CALF];
const unsigned long ACTUATOR_ID_RIGHT_KNEE = ACTUATOR_IDS[RIGHT_KNEE];
const unsigned long ACTUATOR_ID_LEFT_KNEE = ACTUATOR_IDS[LEFT_KNEE];
const unsigned long ACTUATOR_ID_RIGHT_HIP_PITCH = ACTUATOR_IDS[RIGHT_HIP_PITCH];
const unsigned long ACTUATOR_ID_LEFT_HIP_PITCH = ACTUATOR_IDS[LEFT_HIP_PITCH];
const unsigned long ACTUATOR_ID_RIGHT_HIP_YAW = ACTUATOR_IDS[RIGHT_HIP_YAW];
const unsigned long ACTUATOR_ID_LEFT_HIP_YAW = ACTUATOR_IDS[LEFT_HIP_YAW];
const unsigned long ACTUATOR_ID_RIGHT_HIP_ROLL = ACTUATOR_IDS[RIGHT_HIP_ROLL];
const unsigned long ACTUATOR_ID_LEFT_HIP_ROLL = ACTUATOR_IDS[LEFT_HIP_ROLL];

static const uint32_t MOTOR_NATIVE_QUERY_SLOT_MS = 5;
static const uint32_t MOTOR_NATIVE_STALE_MS = 500;
static const uint8_t MOTOR_BOOT_ZERO_SAMPLE_COUNT = 8;
static const float MOTOR_BOOT_ZERO_MAX_SPREAD_DEG = 2.0f;
static const float MOTOR_AS5600_DIVERGENCE_LIMIT_DEG = 12.0f;
static const uint8_t MOTOR_AS5600_DIVERGENCE_SAMPLE_COUNT = 3;
static const uint8_t RIGHT_MOTOR_TELEMETRY_ORDER[6] = {
  RIGHT_OUTER_CALF, RIGHT_INNER_CALF, RIGHT_HIP_PITCH,
  RIGHT_KNEE, RIGHT_HIP_YAW, RIGHT_HIP_ROLL
};
static const uint8_t LEFT_MOTOR_TELEMETRY_ORDER[6] = {
  LEFT_OUTER_CALF, LEFT_INNER_CALF, LEFT_HIP_PITCH,
  LEFT_KNEE, LEFT_HIP_YAW, LEFT_HIP_ROLL
};
volatile float motorNativeDegrees[ACTUATOR_COUNT] = {0.0f};
volatile uint32_t motorNativeReceivedMs[ACTUATOR_COUNT] = {0};
volatile bool motorNativeValid[ACTUATOR_COUNT] = {false};
volatile bool motorControlZeroed[ACTUATOR_COUNT] = {false};
volatile bool motorControlAlignmentFault[ACTUATOR_COUNT] = {false};
volatile float motorControlZeroOffsetDegrees[ACTUATOR_COUNT] = {0.0f};
volatile float motorAs5600ErrorDegrees[ACTUATOR_COUNT] = {0.0f};
volatile uint8_t motorBootZeroSamples[ACTUATOR_COUNT] = {0};
volatile uint8_t motorAs5600DivergenceSamples[ACTUATOR_COUNT] = {0};
float motorBootZeroOffsetSum[ACTUATOR_COUNT] = {0.0f};
float motorBootZeroOffsetMin[ACTUATOR_COUNT] = {0.0f};
float motorBootZeroOffsetMax[ACTUATOR_COUNT] = {0.0f};
volatile uint32_t motorNativeQueries = 0;
volatile uint32_t motorNativeQueryFailures = 0;
volatile uint32_t motorNativeResponses = 0;
volatile uint32_t motorNativeMalformedResponses = 0;

// -----------------------------------------------------------------------------
// Shared state
// -----------------------------------------------------------------------------

struct JointConstraints {
  int minAngle = 0;
  int maxAngle = 360;
};

JointConstraints outerCalfConstraintsLeft;
JointConstraints outerCalfConstraintsRight;
JointConstraints innerCalfConstraintsLeft;
JointConstraints innerCalfConstraintsRight;
JointConstraints kneeConstraintsLeft;
JointConstraints kneeConstraintsRight;
JointConstraints hipPitchConstraintsLeft;
JointConstraints hipPitchConstraintsRight;
JointConstraints hipYawConstraintsLeft;
JointConstraints hipYawConstraintsRight;
JointConstraints hipRollConstraintsLeft;
JointConstraints hipRollConstraintsRight;

// Manual/direct torque setpoints, in the same 0.01 A-ish command units used by
// the existing A1 implementation. maxTorqueLimit=3.0 => +/-300 command units.
volatile int16_t torqueValues[ACTUATOR_COUNT] = {0};
volatile int16_t impedanceTorqueValues[ACTUATOR_COUNT] = {0};

float maxTorqueLimit = 3.0f;

bool isLeft = true;
bool isCenter = false;
bool rawMode = false;
bool playMode = false;
volatile bool telemetryStreamingEnabled = false;
bool configMode = false;

// Stop burst is handled by the CAN output task. Three repeated 0x81 frames are
// used to retain the intent of the previous enterConfigurationMode() behavior.
volatile uint8_t stopBurstRemaining = 0;

// Calibration output override. This keeps calibration from racing against the
// normal torque/impedance output path.
volatile bool calibrationOverrideActive = false;
volatile int calibrationActuatorIndex = -1;
volatile int16_t calibrationTorqueValue = 0;

SemaphoreHandle_t serialMutex = nullptr;
SemaphoreHandle_t canMutex = nullptr;
SemaphoreHandle_t stateMutex = nullptr;

SemaphoreHandle_t webLogMutex = nullptr;
SemaphoreHandle_t spiffsMutex = nullptr;

// True only when a valid LegSide value has been loaded/saved. A fresh device
// boots into DROPBEAR-SETUP and does not start actuator tasks until configured.
bool configProvisioned = false;
String roleAtBoot = "unconfigured";
volatile bool rebootRequired = false;

// These flags describe the task topology actually instantiated at boot.
// Changing role never silently repurposes already-running actuator tasks.
volatile bool runtimeControlReady = false;
volatile bool runtimeImuReady = false;

// -----------------------------------------------------------------------------
// Captive portal / web command plumbing
// -----------------------------------------------------------------------------

DNSServer dnsServer;
WebServer server(80);

IPAddress portalIP(192, 168, 4, 1);
IPAddress portalGateway(192, 168, 4, 1);
IPAddress portalSubnet(255, 255, 255, 0);

static const uint16_t DNS_PORT = 53;
static const size_t WEB_COMMAND_MAX = 192;
static const size_t WEB_LOG_CAPACITY = 96;

struct WebCommand {
  uint32_t id;
  char text[WEB_COMMAND_MAX];
};

struct WebLogEntry {
  uint32_t seq = 0;
  uint32_t ms = 0;
  String text;
};

QueueHandle_t webCommandQueue = nullptr;
WebLogEntry webLog[WEB_LOG_CAPACITY];
size_t webLogHead = 0;
size_t webLogCount = 0;
uint32_t webLogSequence = 0;
uint32_t nextWebCommandId = 1;

volatile bool portalRestartRequested = false;
volatile bool portalRebootRequested = false;
volatile uint32_t portalRebootAtMs = 0;
bool portalRoutesRegistered = false;
String portalSSID = "DROPBEAR-SETUP";

// Command-output capture is only activated while the single command task is
// executing a web command. All human-readable command responses are mirrored
// into the web log as well as USB Serial.
String *activeCommandCapture = nullptr;

String selectedRoleName();
String desiredPortalSSID();
void requestPortalRestart();
void appendWebLog(const String &line);
void dbPrintln(const String &line);
void dbPrintf(const char *format, ...);
void setupPortal();
void portalTask(void *parameter);
void handleConfigurationCommand(String command);
void processSerialCommand(String command);
void readIMU();
void saveConfig();
void printHelp();
void printVersionRecord();
void printHealthRecord();


// -----------------------------------------------------------------------------
// Unified human-readable logging
// -----------------------------------------------------------------------------

void appendWebLog(const String &line) {
  if (line.length() == 0) return;
  if (webLogMutex && xSemaphoreTake(webLogMutex, pdMS_TO_TICKS(20)) != pdTRUE) return;

  WebLogEntry &entry = webLog[webLogHead];
  entry.seq = ++webLogSequence;
  entry.ms = millis();
  entry.text = line;

  webLogHead = (webLogHead + 1) % WEB_LOG_CAPACITY;
  if (webLogCount < WEB_LOG_CAPACITY) ++webLogCount;

  if (webLogMutex) xSemaphoreGive(webLogMutex);
}

void captureCommandText(const String &text) {
  if (!activeCommandCapture) return;
  *activeCommandCapture += text;
}

void dbPrintln(const String &line) {
  Serial.println(line);
  captureCommandText(line + "\n");
  appendWebLog(line);
}

void dbPrintf(const char *format, ...) {
  char buffer[512];
  va_list args;
  va_start(args, format);
  vsnprintf(buffer, sizeof(buffer), format, args);
  va_end(args);

  Serial.print(buffer);
  String text(buffer);
  captureCommandText(text);

  int start = 0;
  while (start < (int)text.length()) {
    int nl = text.indexOf('\n', start);
    if (nl < 0) {
      String tail = text.substring(start);
      tail.trim();
      if (tail.length()) appendWebLog(tail);
      break;
    }
    String line = text.substring(start, nl);
    line.trim();
    if (line.length()) appendWebLog(line);
    start = nl + 1;
  }
}

String selectedRoleName() {
  if (!configProvisioned) return "unconfigured";
  if (isCenter) return "center";
  return isLeft ? "left" : "right";
}

String desiredPortalSSID() {
  if (!configProvisioned) return "DROPBEAR-SETUP";
  if (isCenter) return "CENTER";
  return isLeft ? "LEFTLEG" : "RIGHTLEG";
}

void requestPortalRestart() {
  portalRestartRequested = true;
}

// -----------------------------------------------------------------------------
// Sensor filtering / state
// -----------------------------------------------------------------------------

static const int NUM_READINGS = 10;
int readingsOuter[NUM_READINGS] = {0};
int readingsInner[NUM_READINGS] = {0};
int readingsHip[NUM_READINGS] = {0};
int readingsKnee[NUM_READINGS] = {0};
int readingsButt[NUM_READINGS] = {0};

long totalOuter = 0;
long totalInner = 0;
long totalHip = 0;
long totalKnee = 0;
long totalButt = 0;

float averageOuter = 0.0f;
float averageInner = 0.0f;
float averageHip = 0.0f;
float averageKnee = 0.0f;
float averageButt = 0.0f;

volatile float normalizedOuter = 0.0f;
volatile float normalizedInner = 0.0f;
volatile float normalizedHip = 0.0f;
volatile float normalizedKnee = 0.0f;
volatile float normalizedButt = 0.0f;

int readIndex = 0;

// Original known offsets retained.
int leftLegOffsets[5] = {32, -26, -4, -17, 2};
int rightLegOffsets[5] = {-28, 39, -2, 18, -2};

// -----------------------------------------------------------------------------
// Direction multipliers
// -----------------------------------------------------------------------------

float directionMultiplierRightOuterCalf = 1.0f;
float directionMultiplierRightInnerCalf = 1.0f;
float directionMultiplierLeftOuterCalf = 1.0f;
float directionMultiplierLeftInnerCalf = 1.0f;
float directionMultiplierRightKnee = 1.0f;
float directionMultiplierLeftKnee = 1.0f;
float directionMultiplierRightHipPitch = 1.0f;
float directionMultiplierLeftHipPitch = 1.0f;
float directionMultiplierRightHipRoll = 1.0f;
float directionMultiplierLeftHipRoll = 1.0f;

bool impedanceEnabledRightOuterCalf = false;
bool impedanceEnabledRightInnerCalf = false;
bool impedanceEnabledLeftOuterCalf = false;
bool impedanceEnabledLeftInnerCalf = false;
bool impedanceEnabledRightKnee = false;
bool impedanceEnabledLeftKnee = false;
bool impedanceEnabledRightHipPitch = false;
bool impedanceEnabledLeftHipPitch = false;
bool impedanceEnabledRightHipRoll = false;
bool impedanceEnabledLeftHipRoll = false;

// -----------------------------------------------------------------------------
// Utility helpers
// -----------------------------------------------------------------------------

float adcToDegrees(float adc) {
  // Keep 4096.0 scaling to remain very close to the original map(...4096...).
  return adc * (360.0f / 4096.0f);
}

float wrapAngleFloat(float angle) {
  angle = fmodf(angle, 360.0f);
  if (angle < 0.0f) angle += 360.0f;
  return angle;
}

int wrapAngle(int angle) {
  angle %= 360;
  if (angle < 0) angle += 360;
  return angle;
}

int16_t clampTorqueCommand(float value) {
  const float limit = maxTorqueLimit * 100.0f;
  if (value > limit) value = limit;
  if (value < -limit) value = -limit;
  return static_cast<int16_t>(lroundf(value));
}

bool actuatorBelongsToSelectedLeg(int index) {
  if (index < 0 || index >= ACTUATOR_COUNT || isCenter) return false;
  return isLeft ? ((index & 1) == 1) : ((index & 1) == 0);
}

int firstSelectedActuatorIndex() {
  return isLeft ? 1 : 0;
}

const uint8_t *selectedMotorTelemetryOrder() {
  return isLeft ? LEFT_MOTOR_TELEMETRY_ORDER : RIGHT_MOTOR_TELEMETRY_ORDER;
}

int actuatorIndexFromCanId(uint32_t actuatorID) {
  for (int i = 0; i < ACTUATOR_COUNT; ++i) {
    if (ACTUATOR_IDS[i] == actuatorID) return i;
  }
  return -1;
}

int actuatorIndexFromMotorFeedbackId(uint32_t responseID) {
  if (responseID < 0x100) return -1;
  const int index = actuatorIndexFromCanId(responseID - 0x100);
  return actuatorBelongsToSelectedLeg(index) ? index : -1;
}

int as5600SensorIndexForActuator(int actuatorIndex) {
  switch (actuatorIndex) {
    case RIGHT_OUTER_CALF:
    case LEFT_OUTER_CALF: return 0;
    case RIGHT_INNER_CALF:
    case LEFT_INNER_CALF: return 1;
    case RIGHT_HIP_PITCH:
    case LEFT_HIP_PITCH: return 2;
    case RIGHT_KNEE:
    case LEFT_KNEE: return 3;
    case RIGHT_HIP_ROLL:
    case LEFT_HIP_ROLL: return 4;
    default: return -1;
  }
}

float motorFeedbackDirectionForActuator(int actuatorIndex) {
  switch (actuatorIndex) {
    case RIGHT_OUTER_CALF: return directionMultiplierRightOuterCalf;
    case LEFT_OUTER_CALF: return directionMultiplierLeftOuterCalf;
    case RIGHT_INNER_CALF: return directionMultiplierRightInnerCalf;
    case LEFT_INNER_CALF: return directionMultiplierLeftInnerCalf;
    case RIGHT_KNEE: return directionMultiplierRightKnee;
    case LEFT_KNEE: return directionMultiplierLeftKnee;
    case RIGHT_HIP_PITCH: return directionMultiplierRightHipPitch;
    case LEFT_HIP_PITCH: return directionMultiplierLeftHipPitch;
    case RIGHT_HIP_ROLL: return directionMultiplierRightHipRoll;
    case LEFT_HIP_ROLL: return directionMultiplierLeftHipRoll;
    default: return 1.0f;
  }
}

float normalizedAs5600Degrees(uint8_t sensorIndex) {
  switch (sensorIndex) {
    case 0: return normalizedOuter;
    case 1: return normalizedInner;
    case 2: return normalizedHip;
    case 3: return normalizedKnee;
    case 4: return normalizedButt;
    default: return 0.0f;
  }
}

float shortestAngleDifference(float value, float reference) {
  return fmodf(value - reference + 540.0f, 360.0f) - 180.0f;
}

void resetMotorBootZeroAccumulator(int actuatorIndex) {
  motorBootZeroSamples[actuatorIndex] = 0;
  motorBootZeroOffsetSum[actuatorIndex] = 0.0f;
  motorBootZeroOffsetMin[actuatorIndex] = 0.0f;
  motorBootZeroOffsetMax[actuatorIndex] = 0.0f;
}

void updateMotorControlReference(int actuatorIndex, float nativeDegrees) {
  const int sensorIndex = as5600SensorIndexForActuator(actuatorIndex);
  if (motorControlAlignmentFault[actuatorIndex]) return;
  const float directedNative = nativeDegrees * motorFeedbackDirectionForActuator(actuatorIndex);
  if (sensorIndex < 0) {
    if (!motorControlZeroed[actuatorIndex]) {
      motorControlZeroOffsetDegrees[actuatorIndex] = -directedNative;
      motorControlZeroed[actuatorIndex] = true;
    }
    return;
  }
  const float externalDegrees = normalizedAs5600Degrees(static_cast<uint8_t>(sensorIndex));
  if (!isfinite(externalDegrees)) return;

  if (motorControlZeroed[actuatorIndex]) {
    const float aligned = directedNative + motorControlZeroOffsetDegrees[actuatorIndex];
    const float disagreement = fabsf(shortestAngleDifference(aligned, externalDegrees));
    motorAs5600ErrorDegrees[actuatorIndex] = disagreement;
    if (disagreement > MOTOR_AS5600_DIVERGENCE_LIMIT_DEG) {
      if (motorAs5600DivergenceSamples[actuatorIndex] < UINT8_MAX)
        motorAs5600DivergenceSamples[actuatorIndex]++;
      if (motorAs5600DivergenceSamples[actuatorIndex] >= MOTOR_AS5600_DIVERGENCE_SAMPLE_COUNT) {
        motorControlAlignmentFault[actuatorIndex] = true;
        motorControlZeroed[actuatorIndex] = false;
        impedanceTorqueValues[actuatorIndex] = 0;
      }
    } else {
      motorAs5600DivergenceSamples[actuatorIndex] = 0;
    }
    return;
  }

  float candidateOffset = externalDegrees - directedNative;
  const uint8_t samples = motorBootZeroSamples[actuatorIndex];
  if (samples > 0) {
    const float referenceOffset = motorBootZeroOffsetSum[actuatorIndex] / static_cast<float>(samples);
    candidateOffset = referenceOffset + shortestAngleDifference(candidateOffset, referenceOffset);
  }
  if (samples == 0) {
    motorBootZeroOffsetMin[actuatorIndex] = candidateOffset;
    motorBootZeroOffsetMax[actuatorIndex] = candidateOffset;
  } else {
    motorBootZeroOffsetMin[actuatorIndex] = min(motorBootZeroOffsetMin[actuatorIndex], candidateOffset);
    motorBootZeroOffsetMax[actuatorIndex] = max(motorBootZeroOffsetMax[actuatorIndex], candidateOffset);
  }
  motorBootZeroOffsetSum[actuatorIndex] += candidateOffset;
  motorBootZeroSamples[actuatorIndex] = samples + 1;
  if (motorBootZeroSamples[actuatorIndex] < MOTOR_BOOT_ZERO_SAMPLE_COUNT) return;
  if (motorBootZeroOffsetMax[actuatorIndex] - motorBootZeroOffsetMin[actuatorIndex] >
      MOTOR_BOOT_ZERO_MAX_SPREAD_DEG) {
    resetMotorBootZeroAccumulator(actuatorIndex);
    return;
  }
  motorControlZeroOffsetDegrees[actuatorIndex] = motorBootZeroOffsetSum[actuatorIndex] /
    static_cast<float>(motorBootZeroSamples[actuatorIndex]);
  motorAs5600ErrorDegrees[actuatorIndex] = 0.0f;
  motorAs5600DivergenceSamples[actuatorIndex] = 0;
  motorControlZeroed[actuatorIndex] = true;
}
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
void loop() {
  // All runtime ownership is explicit FreeRTOS tasks.
  vTaskDelay(pdMS_TO_TICKS(1000));
}

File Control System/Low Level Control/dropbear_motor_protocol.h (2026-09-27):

#ifndef DROPBEAR_MOTOR_PROTOCOL_H
#define DROPBEAR_MOTOR_PROTOCOL_H

#include <stddef.h>
#include <stdint.h>

// Pure, allocation-free MyActuator/RMD protocol helpers.  This header has no
// Arduino dependencies so the exact wire codecs can also be tested on a host.
namespace dropbear {

enum AnglePayloadLayout : uint8_t {
  ANGLE_SIGNED_56_LE_BYTES_1_TO_7 = 0,
  ANGLE_SIGNED_32_LE_BYTES_4_TO_7 = 1,
};

enum AngleReference : uint8_t {
  ANGLE_REFERENCE_OUTPUT_SHAFT = 0,
  ANGLE_REFERENCE_MOTOR_SHAFT = 1,
};

enum DecodeStatus : uint8_t {
  DECODE_OK = 0,
  DECODE_INVALID_ARGUMENT,
  DECODE_INVALID_LENGTH,
  DECODE_WRONG_OPCODE,
  DECODE_RESERVED_BYTES_NONZERO,
  DECODE_INVALID_REDUCTION,
};

struct MotorProfile {
  const char *model;
  const char *protocolVersion;
  float reductionRatio;
  AnglePayloadLayout angleLayout;
  AngleReference angleReference;
  float angleLsbDegrees;
  uint8_t readMultiTurnOpcode;
  uint8_t torqueOpcode;
  uint8_t shutdownOpcode;
  uint8_t holdOpcode;
};

inline const char *angleLayoutName(AnglePayloadLayout layout) {
  switch (layout) {
    case ANGLE_SIGNED_56_LE_BYTES_1_TO_7:
      return "signed56_le_bytes_1_7";
    case ANGLE_SIGNED_32_LE_BYTES_4_TO_7:
      return "signed32_le_bytes_4_7";
    default:
      return "unknown";
  }
}

inline const char *angleReferenceName(AngleReference reference) {
  return reference == ANGLE_REFERENCE_MOTOR_SHAFT ? "motor_shaft" : "output_shaft";
}

inline int64_t decodeSigned56LittleEndian(const uint8_t *bytes) {
  uint64_t raw = 0;
  for (uint8_t index = 0; index < 7; ++index) {
    raw |= static_cast<uint64_t>(bytes[index]) << (index * 8);
  }
  if ((raw & (1ULL << 55)) == 0) return static_cast<int64_t>(raw);
  const uint64_t magnitude = ((~raw) & ((1ULL << 56) - 1ULL)) + 1ULL;
  return -static_cast<int64_t>(magnitude);
}

inline int64_t decodeSigned32LittleEndian(const uint8_t *bytes) {
  const uint32_t raw = static_cast<uint32_t>(bytes[0]) |
                       (static_cast<uint32_t>(bytes[1]) << 8) |
                       (static_cast<uint32_t>(bytes[2]) << 16) |
                       (static_cast<uint32_t>(bytes[3]) << 24);
  return (raw & 0x80000000UL)
    ? static_cast<int64_t>(raw) - 0x100000000LL
    : static_cast<int64_t>(raw);
}

inline DecodeStatus outputShaftDegrees(const MotorProfile &profile,
                                       double reportedDegrees,
                                       double *outputDegrees) {
  if (outputDegrees == nullptr) return DECODE_INVALID_ARGUMENT;
  if (profile.angleReference == ANGLE_REFERENCE_OUTPUT_SHAFT) {
    *outputDegrees = reportedDegrees;
    return DECODE_OK;
  }
  if (!(profile.reductionRatio > 0.0f)) return DECODE_INVALID_REDUCTION;
  *outputDegrees = reportedDegrees / static_cast<double>(profile.reductionRatio);
  return DECODE_OK;
}

inline DecodeStatus decodeMultiTurnAngle(const MotorProfile &profile,
                                         const uint8_t *payload,
                                         size_t length,
                                         double *outputDegrees) {
  if (payload == nullptr || outputDegrees == nullptr) return DECODE_INVALID_ARGUMENT;
  if (length != 8) return DECODE_INVALID_LENGTH;
  if (payload[0] != profile.readMultiTurnOpcode) return DECODE_WRONG_OPCODE;

  int64_t rawAngle = 0;
  switch (profile.angleLayout) {
    case ANGLE_SIGNED_56_LE_BYTES_1_TO_7:
      rawAngle = decodeSigned56LittleEndian(payload + 1);
      break;
    case ANGLE_SIGNED_32_LE_BYTES_4_TO_7:
      if (payload[1] != 0 || payload[2] != 0 || payload[3] != 0) {
        return DECODE_RESERVED_BYTES_NONZERO;
      }
      rawAngle = decodeSigned32LittleEndian(payload + 4);
      break;
    default:
      return DECODE_INVALID_ARGUMENT;
  }

  return outputShaftDegrees(
    profile,
    static_cast<double>(rawAngle) * static_cast<double>(profile.angleLsbDegrees),
    outputDegrees
  );
}

inline DecodeStatus decodeMultiTurnAngleWithLayout(
    const MotorProfile &profile,
    AnglePayloadLayout layout,
    const uint8_t *payload,
    size_t length,
    double *outputDegrees) {
  MotorProfile detected = profile;
  detected.angleLayout = layout;
  return decodeMultiTurnAngle(detected, payload, length, outputDegrees);
}

inline void encodeReadMultiTurnAngle(const MotorProfile &profile, uint8_t payload[8]) {
  for (uint8_t index = 0; index < 8; ++index) payload[index] = 0;
  payload[0] = profile.readMultiTurnOpcode;
}

inline void encodeTorqueCommand(const MotorProfile &profile,
                                int16_t torqueValue,
                                uint8_t payload[8]) {
  for (uint8_t index = 0; index < 8; ++index) payload[index] = 0;
  const uint16_t wireValue = static_cast<uint16_t>(torqueValue);
  payload[0] = profile.torqueOpcode;
  payload[4] = static_cast<uint8_t>(wireValue & 0xFF);
  payload[5] = static_cast<uint8_t>((wireValue >> 8) & 0xFF);
}

inline void encodeShutdownCommand(const MotorProfile &profile, uint8_t payload[8]) {
  for (uint8_t index = 0; index < 8; ++index) payload[index] = 0;
  payload[0] = profile.shutdownOpcode;
}

inline void encodeHoldCommand(const MotorProfile &profile, uint8_t payload[8]) {
  for (uint8_t index = 0; index < 8; ++index) payload[index] = 0;
  payload[0] = profile.holdOpcode;
}

// Source compatibility for callers that historically called the closed-loop
// 0x81 operation "stop". It is a hold, not an output shutdown.
inline void encodeStopCommand(const MotorProfile &profile, uint8_t payload[8]) {
  encodeHoldCommand(profile, payload);
}

}  // namespace dropbear

#endif  // DROPBEAR_MOTOR_PROTOCOL_H

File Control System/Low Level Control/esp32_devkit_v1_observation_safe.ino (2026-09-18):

#include <Arduino.h>
#include <mcp_can.h>
#include <SPI.h>
#include <SPIFFS.h>
#include <Wire.h>
#include <WiFi.h>
#include <freertos/FreeRTOS.h>
#include <freertos/task.h>

static const char *DROPBEAR_FIRMWARE_VERSION =
  "observation-safe-db2-protocol-2026.09.18";
static const char *DROPBEAR_COMMAND_PROTOCOL = "LEGACY";
static const char *DROPBEAR_TELEMETRY_PROTOCOL = "DB2";
static const char *DROPBEAR_CAPABILITIES =
  "version-v1;health-v1;observe-stream-v1;motor-angle-rmd-v17-v42-0x92;observation-only";

// Struct to hold joint constraints
struct JointConstraints {
  int minAngle = 0;    // Default to 0
  int maxAngle = 360;  // Default to 360
};

// Joint constraints for each joint
JointConstraints outerCalfConstraintsLeft;
JointConstraints outerCalfConstraintsRight;
JointConstraints innerCalfConstraintsLeft;
JointConstraints innerCalfConstraintsRight;
JointConstraints kneeConstraintsLeft;
JointConstraints kneeConstraintsRight;
JointConstraints hipPitchConstraintsLeft;
JointConstraints hipPitchConstraintsRight;
JointConstraints hipYawConstraintsLeft;
JointConstraints hipYawConstraintsRight;
JointConstraints hipRollConstraintsLeft;
JointConstraints hipRollConstraintsRight;

// Constants for IMU handling
#define IMU_COUNT 5
#define I2C_SDA_PIN 21
#define I2C_SCL_PIN 22

#define CAN0_INT GPIO_NUM_17  // Set INT to gpio pin 17
MCP_CAN CAN(GPIO_NUM_5);      // Set CS to gpio pin 5

// Actuator IDs for right, left leg and IMUs
const long unsigned int ACTUATOR_ID_RIGHT_CALF_OUTER = 0x144;
const long unsigned int ACTUATOR_ID_LEFT_CALF_OUTER = 0x141;
const long unsigned int ACTUATOR_ID_RIGHT_CALF_INNER = 0x143;
const long unsigned int ACTUATOR_ID_LEFT_CALF_INNER = 0x142;
const long unsigned int ACTUATOR_ID_RIGHT_KNEE = 0x148;
const long unsigned int ACTUATOR_ID_LEFT_KNEE = 0x145;
const long unsigned int ACTUATOR_ID_RIGHT_HIP_PITCH = 0x147;
const long unsigned int ACTUATOR_ID_LEFT_HIP_PITCH = 0x146;
const long unsigned int ACTUATOR_ID_RIGHT_HIP_YAW = 0x14C;
const long unsigned int ACTUATOR_ID_LEFT_HIP_YAW = 0x149;
const long unsigned int ACTUATOR_ID_RIGHT_HIP_ROLL = 0x14B;
const long unsigned int ACTUATOR_ID_LEFT_HIP_ROLL = 0x14A;

const size_t ACTUATOR_COUNT = 12;
const long unsigned int ACTUATOR_IDS[ACTUATOR_COUNT] = {
  ACTUATOR_ID_RIGHT_CALF_OUTER,
  ACTUATOR_ID_LEFT_CALF_OUTER,
  ACTUATOR_ID_RIGHT_CALF_INNER,
  ACTUATOR_ID_LEFT_CALF_INNER,
  ACTUATOR_ID_RIGHT_KNEE,
  ACTUATOR_ID_LEFT_KNEE,
  ACTUATOR_ID_RIGHT_HIP_PITCH,
  ACTUATOR_ID_LEFT_HIP_PITCH,
  ACTUATOR_ID_RIGHT_HIP_YAW,
  ACTUATOR_ID_LEFT_HIP_YAW,
  ACTUATOR_ID_RIGHT_HIP_ROLL,
  ACTUATOR_ID_LEFT_HIP_ROLL,
};

// Motion stays unavailable through the legacy text console. A future typed,
// leased gateway must replace this path before physical output is re-enabled.
const bool OBSERVATION_ONLY_FIRMWARE = true;
const bool LEGACY_SERIAL_MOTION_ALLOWED = false;
// A 0x92 angle request transmits on CAN but cannot command motion. Continuous
// motor-native feedback is enabled so AS5600 can establish the post-restart
// reference while actuator encoders provide the ongoing position stream.
const bool MOTOR_FEEDBACK_QUERY_ALLOWED = true;
bool canReady = false;
bool chiralityConfigured = false;
bool telemetryStreamingEnabled = true;
uint32_t motorQueryCount = 0;
uint32_t motorResponseCount = 0;
uint32_t motorQueryFailureCount = 0;
uint32_t malformedMotorResponseCount = 0;
uint16_t canConsecutiveFailures = 0;

const uint32_t TELEMETRY_PERIOD_MS = 20;  // 50 Hz; values are degrees on the wire.
const uint32_t MOTOR_QUERY_PERIOD_MS = 5;
const uint32_t MOTOR_FEEDBACK_STALE_MS = 500;
const size_t OWNED_ACTUATOR_COUNT = 6;
const size_t RIGHT_TELEMETRY_INDICES[OWNED_ACTUATOR_COUNT] = { 0, 2, 6, 4, 8, 10 };
const size_t LEFT_TELEMETRY_INDICES[OWNED_ACTUATOR_COUNT] = { 1, 3, 7, 5, 9, 11 };

float motorNativeDegrees[ACTUATOR_COUNT] = { 0 };
uint32_t motorNativeReceivedMs[ACTUATOR_COUNT] = { 0 };
bool motorNativeValid[ACTUATOR_COUNT] = { false };

bool isKnownActuatorId(long unsigned int actuatorID) {
  for (size_t i = 0; i < ACTUATOR_COUNT; ++i) {
    if (ACTUATOR_IDS[i] == actuatorID) return true;
  }
  return false;
}

// Variables to store torque values for each actuator
int16_t torqueValues[ACTUATOR_COUNT] = { 0 };

// Maximum torque limit in amps (adjustable via command)
float maxTorqueLimit = 3.0;

// Sensor readings
int outerCalf = 14;
int innerCalf = 27;
int hip = 26;
int knee = 25;
int butt = 33;

bool isLeft = true;
bool isCenter = false;
bool rawMode = false;  // To track whether raw mode is enabled
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

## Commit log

2024-05-10 Pushed local files
    [3.iges, 4.iges, Actuator Housing.stl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]
2024-05-10 Added CAD files with git-lfs
    [10_Box_Base.stl, 11_Base_Legs.stl, 1_Fore_Finger.stl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]
2024-05-10 Work in progress files
    [Assem1.SLDASM, BackThigh.step, Calf-support - Copy.step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]
2024-05-20 Torso and waist Simulation in RViz
    Set up a humanoid xacro file that links (for now) torso and the waist for joint manipulation and simulation.
    [Buttocks_1.stl, DumHead_1.stl, DumLArm_1.stl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]
2024-06-05 Added Fusion leg model and cleaned old sim reports
    [3.iges, 4.iges, Calf_1.iges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]
2024-06-06 Updated Arms, URDF, Added motion in Altair, etc.
    - Updated URDF, now with legs, right arm, etc. (WIP)
    - Tested Arm motion in Fusion360 & Altair Inspire.
    [10_Box_Base.stl, 11_Base_Legs.stl, 1_Fore_Finger.stl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]
2024-06-07 URDF for left leg and left hand.
    Added right and left leg tried using mirroring which broke everything initially but now works. The joint publisher screen appears has all the joints for pitch, roll, yaw of left and right legs and arms.
    [2020_100mm_MIR_1.stl, 2020_100mm__10__1.stl, 2020_100mm__11__1.stl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]
2024-06-07 Added showcase video
    Added a video showing all joints visualized from the URDF in Rviz
2024-07-09 2 new RViz URDFs
    One with references to simplified meshes
    One with each individual mesh reference (useful for assigning properties to each part in Isaac sim)
    [00_top_lvl_p3737_01142022_1.stl, 100m_1.stl, 100m__1__1.stl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]
2024-08-14 Updated URDFs for full body
    URDFs for Gazebo sim with <gazebo> tags for closed chain kinematics in Gazebo to get an SDF.
    [00_top_lvl_p3737_01142022_1.stl, 100m_1.stl, 100m__1__1.stl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]
2024-08-22 Added Gazebo sim files.
    URDF for gazebo
    [00_top_lvl_p3737_01142022_1.stl, 100m_1.stl, 100m__1__1.stl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]
2024-09-02 Actuator profiles + resources
    - Added more resources for interfacing with the actuators.
    - Added ratios etc.
    [RMD-X10-S2 V3.step, Ratios.xlsx, X10-100(RMD-X10-S2 V3).step]
2024-09-05 added encoder direction calibration features, motors stopped by default when script begins
2024-11-12 Track large Fusion360 files with Git LFS
    [FullHumanoidIndividualParts v6 v1.f3d, V3 Assembly Full body v2.f3z]
2024-11-12 Assigned materials to Fusion model and exported ROS2-compatible URDF using fusion2urdf addon. Scripted mass updates from Fusion's URDF to current version. Added hands and leg controllers with joint p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
    [00_top_lvl_p3737_01142022_1.stl, 100m_1.stl, 100m__1__1.stl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]
2024-11-28 Create Assembly guide- Right Arm.pdf
2024-12-24 New sim incoming!
    Wrote some ros nodes for joint trajectory control. Had a nightmare fixing closed loop chain joints but is now fully working in gz! Bringing into mujoco and isaac labs is on todo cuz some prismatic & other joints are not being translated correctly. Will try to play around with more plugins and extensions to get there!
    [100m_1.stl, 100m__1__1.stl, 100m__2__1.stl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]
2025-02-21 OpenQDD Actuator Testing
2025-03-26 transient filtering, calibration and other commands
2026-09-15 Make leg firmware fail closed and stage dual-angle telemetry
    [esp32_devkit_v1.ino]
2026-09-16 Add motor-native angle telemetry to Behemoth
2026-09-16 Fix hybrid firmware Arduino compilation
    [esp32_devkitc_v4_hybrid.ino]
2026-09-16 Use CAN-native position feedback across leg firmware
2026-09-16 Document dashboard workflow and preserve ESP32 settings
    [partitions.csv]
2026-09-17 Add versioned live motor observation protocol
2026-09-18 Decode legacy X8 motor angle feedback
2026-09-25 Harden Behemoth motor feedback telemetry
2026-09-26 Add modular motor diagnostics and guarded config protocol
2026-09-26 Allow read-only diagnostics for discovered motor IDs
2026-09-26 Harden MCP2515 multi-motor CAN lifecycle
2026-09-27 feat: discover RMD motor firmware variants
2026-09-27 Stabilize multi-motor CAN observation

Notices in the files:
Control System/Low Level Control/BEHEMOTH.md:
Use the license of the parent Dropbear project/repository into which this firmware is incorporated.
